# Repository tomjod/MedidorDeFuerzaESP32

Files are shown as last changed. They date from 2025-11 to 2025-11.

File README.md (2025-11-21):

# Medidor de Fuerza H:Q (Isquiotibiales / Cuádriceps)

## Descripción del Proyecto

Este proyecto consiste en un dispositivo electrónico diseñado para la medición, visualización y análisis de la fuerza muscular, específicamente enfocado en la relación (ratio) entre los músculos Isquiotibiales y Cuádriceps. Es una herramienta orientada a la evaluación biomecánica y rehabilitación deportiva.

El sistema utiliza celdas de carga para medir la fuerza ejercida en tiempo real, procesa los datos mediante un microcontrolador ESP32 y presenta los resultados en una pantalla de alta resolución con una interfaz gráfica moderna. Además, transmite los datos vía Bluetooth para su registro y análisis externo.

## Componentes de Hardware

### Microcontrolador

- **ESP32 DevKit V1**: Seleccionado por su doble núcleo (potencia de procesamiento), conectividad Bluetooth nativa y gran cantidad de pines GPIO.

### Sensores

- **2x Celdas de Carga (Tipo S)**: Transductores que convierten la fuerza física en una señal eléctrica diferencial.
- **2x Módulos HX711**: Amplificadores de instrumentación de 24-bits que digitalizan la señal de las celdas de carga para que el ESP32 pueda leerla con alta precisión.

### Visualización

- **Pantalla TFT ST7789 (170x320 píxeles)**: Pantalla IPS a color de alta densidad. Se eligió por su excelente ángulo de visión y capacidad de refresco rápido.

### Interfaz Física

- **Botón de Tara**: Para calibrar el cero de los sensores antes de la medición.
- **LEDs Indicadores**:
  - LED Estado (Heartbeat).
  - LED Bluetooth (Indica conexión activa).

## Diagrama de Conexiones (Pinout)

| Componente | Pin Dispositivo | Pin ESP32 | Descripción |
| :--- | :--- | :--- | :--- |
| **Sensor Isquios** | DAT | GPIO 19 | Datos HX711 |
| | CLK | GPIO 5 | Reloj HX711 |
| **Sensor Cuads** | DAT | GPIO 21 | Datos HX711 |
| | CLK | GPIO 22 | Reloj HX711 |
| **Pantalla ST7789** | SDA | GPIO 13 | Serial Data |
| | SCL | GPIO 14 | Serial Clock |
| | CS | (No conectado) | Chip Select (Opcional) |
| | DC | GPIO 26 | Data/Command |
| | RST | GPIO 27 | Reset |
| **Controles** | Botón Tara | GPIO 32 | Pull-up interno activado |
| | LED Estado | GPIO 4 | Indicador de funcionamiento |
| | LED Bluetooth | GPIO 23 | Indicador de conexión |

## Arquitectura de Software y Librerías

El firmware está desarrollado en C++ utilizando el framework Arduino sobre PlatformIO. Se han seleccionado librerías específicas para garantizar rendimiento y estabilidad:

### 1. `TFT_eSPI` (Bodmer)

- **Por qué se usa**: Es la librería gráfica más rápida disponible para el ESP32. Permite el uso de **Sprites** (buffers de memoria de video), lo que elimina el parpadeo ("flicker") al actualizar la pantalla.
- **Implementación**: Se dibuja toda la interfaz (medidores, textos, arcos) en un Sprite de 320x170 píxeles en la memoria RAM y luego se envía de golpe a la pantalla (DMA), logrando animaciones fluidas.

### 2. `HX711_ADC` (Olkal)

- **Por qué se usa**: A diferencia de la librería HX711 estándar, esta versión es **no bloqueante**. Permite leer los sensores sin detener el resto del programa (como la actualización de la pantalla o el Bluetooth).
- **Características**: Incluye algoritmos de suavizado (smoothing) para reducir el ruido eléctrico y estabilizar la lectura del peso.

### 3. `BluetoothSerial` (Nativa)

- **Por qué se usa**: Implementa el protocolo Bluetooth Clásico (SPP - Serial Port Profile), permitiendo que el dispositivo se comunique con teléfonos Android o PCs como si fuera un cable serial. Ideal para enviar datos de telemetría en tiempo real.

### 4. `Preferences` (Nativa)

- **Por qué se usa**: Reemplaza a la antigua EEPROM. Permite guardar los factores de calibración en la memoria no volátil (NVS) del ESP32, asegurando que la calibración no se pierda al apagar el dispositivo.

## Lógica de Funcionamiento

1. **Inicialización**: Al encender, el sistema carga la calibración guardada, inicia la pantalla y tara (pone a cero) los sensores.
2. **Bucle Principal (Loop)**:
    - **Lectura**: Lee los sensores HX711.
    - **Filtrado (Deadzone)**: Se aplica un umbral mínimo de **3 Newtons**. Cualquier fuerza menor a esto se considera ruido y se muestra como 0N.
    - **Cálculo**: Convierte la señal eléctrica a Newtons usando el factor de calibración y la constante de gravedad (9.81).
    - **Ratio H:Q**: Calcula la relación `Fuerza Isquios / Fuerza Cuádriceps`.
        - *Ejemplo*: Si Isquios = 100N y Cuads = 200N, Ratio = 0.5.
    - **Visualización**: Dibuja dos medidores circulares ("Gauges") y el valor numérico central. El color del ratio cambia según si está en un rango saludable o no.
    - **Transmisión**: Envía un paquete de datos binarios por Bluetooth para ser graficado en una App externa.

## Instrucciones de Uso

1. **Encendido**: Conectar el dispositivo a una fuente USB o batería.
2. **Tara**: Asegurarse de que no haya carga en los sensores y presionar el **Botón de Tara**. La pantalla indicará "Tarando...".
3. **Medición**: Aplicar fuerza en los sensores. Los gráficos se llenarán en tiempo real.
4. **Conexión App**:
    - Buscar dispositivo Bluetooth "ESP32_Fuerza_HQ".
    - Conectar desde la aplicación de análisis.
    - El LED de Bluetooth se encenderá fijo.

## Calibración (Técnica)

El sistema permite calibración remota vía comandos Serial/Bluetooth:

- `t`: Tarar sensores.
- `i=XXXX.X`: Establecer factor de calibración para Isquios.
- `q=XXXX.X`: Establecer factor de calibración para Cuádriceps.
- `save`: Guardar configuración en memoria permanente.

---

*Proyecto desarrollado por Alexis Ocando para Andrea Zunino*

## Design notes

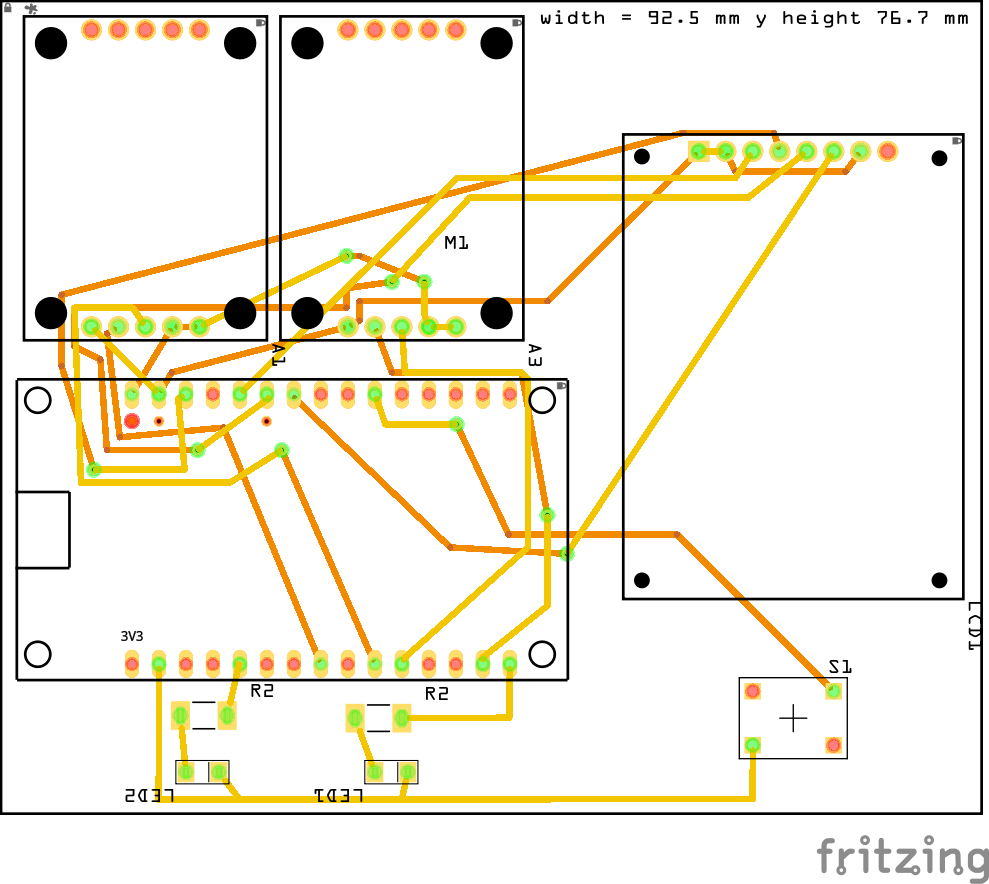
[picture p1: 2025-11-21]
pcb.png

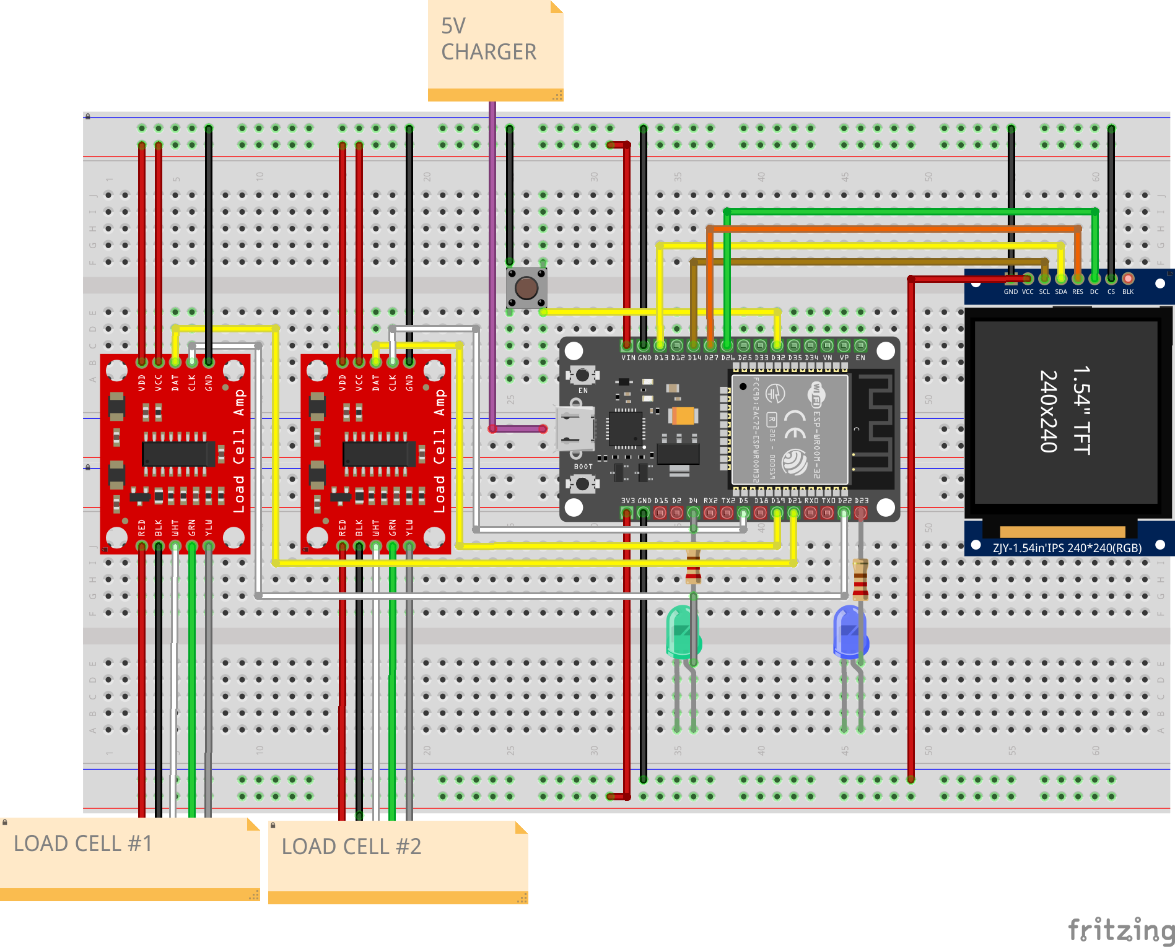
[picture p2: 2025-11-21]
protoboard_connection.png

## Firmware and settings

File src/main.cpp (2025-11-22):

/*
 * PROYECTO: Medidor de Fuerza H:Q (Isquios/Cuádriceps)
 * MCU: ESP32 DevKit V1
 * PANTALLA: ST7789 170x320
 * SENSORES: 2x Celdas de Carga "S" + 2x SparkFun HX711
 * CONTROLES: 1x Botón (Tara), 2x LEDs (Estado, BT)
 *
 * AUTOR: Ing. Alexis Ocando
 */
#include "BluetoothSerial.h" 

#if !defined(CONFIG_BT_ENABLED) || !defined(CONFIG_BLUEDROID_ENABLED)
#error Bluetooth is not enabled! Please run `make menuconfig` to and enable it
#endif
 
#if !defined(CONFIG_BT_SPP_ENABLED)
#error Serial Bluetooth not available or not enabled. It is only available for the ESP32 chip.
#endif

// --- LIBRERÍAS ---
#include <Arduino.h>
#include <HX711_ADC.h> // Librería avanzada para los sensores
#include <TFT_eSPI.h>  // Librería optimizada para la pantalla
#include <SPI.h>
#include <Preferences.h> // Para guardar calibración en NVS


// --- CONFIGURACIÓN DE PINES (SENSORES) ---
const int PIN_ISQUIOS_DAT = 19;
const int PIN_ISQUIOS_CLK = 5;
const int PIN_CUADS_DAT = 21;
const int PIN_CUADS_CLK = 22;

// --- CONFIGURACIÓN DE PINES (CONTROLES) ---
const int PIN_BTN_TARE = 32;
const int PIN_LED_STATUS = 4;  
const int PIN_LED_BT = 23;    

// --- OBJETOS GLOBALES ---
TFT_eSPI tft = TFT_eSPI();
TFT_eSprite sprite = TFT_eSprite(&tft);
BluetoothSerial SerialBT;
HX711_ADC sensorIsquios(PIN_ISQUIOS_DAT, PIN_ISQUIOS_CLK);
HX711_ADC sensorCuads(PIN_CUADS_DAT, PIN_CUADS_CLK);
Preferences preferences;

// --- CALIBRACIÓN ---
volatile float CAL_FACTOR_ISQUIOS = 43082.0; // Compr
volatile float CAL_FACTOR_CUADS = 43540.0;   

// --- VARIABLES GLOBALES (TIMERS) ---
unsigned long lastDisplayTime = 0;
const int DISPLAY_INTERVAL_MS = 100; // 10 FPS

unsigned long lastLedBlinkTime = 0;
unsigned long lastLedBtTime = 0;
const int LED_BLINK_INTERVAL_MS = 1000; // 1 segundo
bool ledStatusState = LOW;
bool ledBTState = LOW;
bool lastBTState = false;
float ratio = 0.0;

// --- VARIABLES GLOBALES (BOTÓN DEBOUNCE) ---
int lastButtonState = HIGH;
unsigned long lastDebounceTime = 0;
const int DEBOUNCE_DELAY_MS = 100;

// --- MODO CALIBRACIÓN ---
bool calibrationMode = false;

// --- DEFINICIÓN DEL PAQUETE BINARIO ---
#define STX 0x02 // STX
#define ETX 0x03 // ETX
#define PAYLOAD_LEN 8 // 2 floats * 4 bytes/float = 8 bytes

const float GRAVITY = 9.81; // Factor de conversión Kg -> Newtons

// --- Declaraciones de funciones ---
void initDisplay();
void initSensors();
void initControls();
void initBluetooth();
void tareSensors();
void handleTareButton();
void handleLEDs();
void handleBluetooth();
void handleSensorDisplay();
void updateBTdisplay();
void drawStaticUI();
void loadCalibration(); 
void saveCalibration(); 
void sendBinaryData(float f_isquios, float f_cuads);
void updateDisplay(float fuerzaIsquios, float fuerzaCuads);
void showCalibrationScreen();



//=================================================================
//  SETUP
//=================================================================
void setup() {
  Serial.begin(19200);
  Serial.println("Iniciando Medidor de Fuerza H:Q (v2.1)...");

  // Cargo la calibración que tengo guardada
  preferences.begin("fuerza-hq", false); // false = read/write
  loadCalibration();

  initControls(); // LEDs y botón
  initDisplay();
  // BT
  initBluetooth();
  initSensors();

}

//=================================================================
//  LOOP
//=================================================================
void loop() {
  
  // 1. Botón de tara (con debounce)
  handleTareButton();

  // 2. Comandos por BT
  handleBluetooth();
  
  // 3. LEDs de estado
  handleLEDs();
  
  // 4. Leer sensores y actualizar pantalla
  handleSensorDisplay();

  // 5. Estado de BT
  updateBTdisplay();

  delay(10);
}

//=================================================================
//  FUNCIONES DE INICIALIZACIÓN
//=================================================================

void initControls() {
  pinMode(PIN_LED_STATUS, OUTPUT);
  pinMode(PIN_LED_BT, OUTPUT);
  pinMode(PIN_BTN_TARE, INPUT_PULLUP); 
}

void initDisplay() {
  tft.init();
  tft.setRotation(1); 
  tft.fillScreen(TFT_BLACK);
  tft.setTextColor(TFT_WHITE, TFT_BLACK); 
  tft.setTextSize(2);
  tft.println("Iniciando...");  
  sprite.createSprite(320, 170);
  delay(1000);
}

void initSensors() {
  Serial.println("Iniciando sensores...");
  tft.println("Iniciando sensores...");

  sensorIsquios.begin();
  sensorIsquios.setGain(128);
  sensorIsquios.setCalFactor(CAL_FACTOR_ISQUIOS);
  sensorIsquios.setReverseOutput(); // Invertir salida para tracción
  sensorIsquios.start(2000, true); // 2s para estabilizar
  if (sensorIsquios.getTareTimeoutFlag()) {
    Serial.println("Error S1 Timeout");
    tft.println("Error S1 Timeout");
  }

  sensorCuads.begin();
  sensorCuads.setGain(128);
  sensorCuads.setCalFactor(CAL_FACTOR_CUADS);
  sensorCuads.setReverseOutput(); // Invertir salida para tracción
  sensorCuads.start(2000, true); // 2s para estabilizar
  if (sensorCuads.getTareTimeoutFlag()) {
    Serial.println("Error S2 Timeout");
    tft.println("Error S2 Timeout");
  }

  // Espero a que estén listos
  unsigned long startWait = millis();
  while(millis() - startWait < 3000) { 
    sensorIsquios.update();
    sensorCuads.update();
    if(sensorIsquios.getDataSetStatus() && sensorCuads.getDataSetStatus()) break;
    delay(10);
  }

  Serial.println("Sensores tarados y listos.");
  delay(1000);
  tft.fillScreen(TFT_BLACK);
}

void initBluetooth() {
  Serial.println("Iniciando Bluetooth...");
  tft.println("Iniciando Bluetooth...");
  if (SerialBT.begin("ESP32_Fuerza_HQ")) {
    Serial.println("Bluetooth iniciado. Listo para conectar.");
  }
  delay(1000);
}

//=================================================================
//  FUNCIONES PRINCIPALES
//=================================================================

// Reviso el botón de tara con debounce
void handleTareButton() {
  int reading = digitalRead(PIN_BTN_TARE);
  
  if (reading != lastButtonState) {
    lastDebounceTime = millis();
    lastButtonState = reading;
  }

  if ((millis() - lastDebounceTime) > DEBOUNCE_DELAY_MS) {
    if (lastButtonState == LOW) {
      tareSensors();
    }
  }
}

// Reviso comandos que llegan por Serial o BT
void handleBluetooth() {
  char cmdChar = ' ';
  String cmdString = "";

  // Desde la PC
  if (Serial.available() > 0) {
    cmdString = Serial.readStringUntil('\n');
    cmdChar = cmdString.charAt(0); // Para compatibilidad con 't'
  }
  
  // Desde el teléfono
  if (SerialBT.available() > 0) {
    cmdString = SerialBT.readStringUntil('\n');
    cmdChar = cmdString.charAt(0); // Para compatibilidad con 't'
  }

  // Proceso el comando
  cmdString.trim();

  if (cmdChar == 't') { // Comando de Tara
    tareSensors();
  }
  else if (cmdString.startsWith("i=")) { // Ajustar Isquios
    float nuevoFactor = cmdString.substring(2).toFloat();
    if (nuevoFactor > 1000) { 
      CAL_FACTOR_ISQUIOS = nuevoFactor;
      sensorIsquios.setCalFactor(CAL_FACTOR_ISQUIOS); 
      Serial.print("Nuevo factor Isquios: ");
      Serial.println(CAL_FACTOR_ISQUIOS);
    }
  }
  else if (cmdString.startsWith("q=")) { // Ajustar Cuádriceps
    float nuevoFactor = cmdString.substring(2).toFloat();
    if (nuevoFactor > 1000) { 
      CAL_FACTOR_CUADS = nuevoFactor;
      sensorCuads.setCalFactor(CAL_FACTOR_CUADS);
      Serial.print("Nuevo factor Cuads: ");
      Serial.println(CAL_FACTOR_CUADS);
    }
  }
  else if (cmdString == "save") { // Guardar
    saveCalibration();
  }
  else if (cmdString == "load") { // Recargar
    loadCalibration();
  }
  else if (cmdString == "cal") { // Modo Calibración
    calibrationMode = !calibrationMode;
    if (calibrationMode) {
      Serial.println("Modo Calibración ACTIVADO - Mostrando valores RAW");
      if (SerialBT.connected()) {
        SerialBT.println("Modo Calibración ACTIVADO");
      }
    } else {
      Serial.println("Modo Calibración DESACTIVADO");
      if (SerialBT.connected()) {
        SerialBT.println("Modo Calibración DESACTIVADO");
      }
      tft.fillScreen(TFT_BLACK);
    }
  }
}

// LEDs de estado
void handleLEDs() {
  // LED BT: encendido si está conectado
  if (SerialBT.connected()) {
    digitalWrite(PIN_LED_BT, HIGH);
  } else {
    if (millis() - lastLedBtTime >= (LED_BLINK_INTERVAL_MS - 500)) {
      lastLedBtTime = millis();
      ledBTState = !ledBTState;
      digitalWrite(PIN_LED_BT, ledBTState );
    }
  }

  if (!ledStatusState) {
    digitalWrite(PIN_LED_STATUS, HIGH);
    ledStatusState = true;
  } 
}

// Leo sensores, actualizo pantalla y mando data por BT
void handleSensorDisplay() {
  if (millis() - lastDisplayTime >= DISPLAY_INTERVAL_MS) {
    lastDisplayTime = millis();
    sensorIsquios.update();
    sensorCuads.update();

    // Si estoy en modo calibración, muestro valores RAW
    if (calibrationMode) {
      showCalibrationScreen();
      return;
    }

    // Obtengo el valor y lo paso a Newtons
    float rawIsquios = sensorIsquios.getData() * GRAVITY;
    float rawCuads = sensorCuads.getData() * GRAVITY;

    // Deadzone de 3N para filtrar ruido
    float fuerzaIsquios = (rawIsquios > 3.0) ? rawIsquios : 0.0f;
    float fuerzaCuads = (rawCuads > 3.0) ? rawCuads : 0.0f;

    // Actualizo pantalla
    updateDisplay(fuerzaIsquios, fuerzaCuads);

    // Mando por BT
    sendBinaryData(fuerzaIsquios, fuerzaCuads);

  }
}

//=================================================================
//  FUNCIONES DE ACCIÓN
//=================================================================

// Tara de los sensores
void tareSensors() {
  Serial.println("Tarando sensores...");
  tft.fillScreen(TFT_BLACK);
  tft.setCursor(tft.width() / 2 - 50, tft.height() / 2 - 10);
  tft.setTextSize(2);
  tft.setTextColor(TFT_WHITE, TFT_BLACK);
  tft.println("Tarando...");
  
  sensorIsquios.tare();
  sensorCuads.tare();

  delay(500); 
  tft.fillScreen(TFT_BLACK);
  Serial.println("Tara completa.");
  
  // Confirmo por BT
  if(SerialBT.connected()) {
    SerialBT.println("Tara Completa");
    SerialBT.write(0x06); // ACK
    SerialBT.flush();
  }
}

// Dibujo un gauge circular
void drawGauge(int x, int y, int r, float val, float maxVal, uint16_t color, String label, String units) {
  int ir = r - 10;
  int startAngle = 135;
  int endAngle = 45;
  
  // Fondo
  sprite.drawSmoothArc(x, y, r, ir, startAngle, endAngle, TFT_DARKGREY, TFT_BLACK, true);

  // Mapeo el valor a un ángulo (270 grados de recorrido)
  
  float percentage = val / maxVal;
  if (percentage > 1.0) percentage = 1.0;
  
  int arcLength = 270;
  int currentEndAngle = startAngle + (int)(percentage * arcLength);
  if (currentEndAngle >= 360) currentEndAngle -= 360;

  // Arco con el valor actual
  if (val > 0.5) { 
      sprite.drawSmoothArc(x, y, r, ir, startAngle, currentEndAngle, color, TFT_BLACK, true);
  }

  // Valor
  sprite.setTextDatum(MC_DATUM); // Middle Center
  sprite.setTextColor(TFT_WHITE, TFT_BLACK);
  sprite.setTextSize(3);
  sprite.drawString(String(val, 0), x, y);
  
  // Unidades
  sprite.setTextSize(1);
  sprite.setTextColor(TFT_LIGHTGREY, TFT_BLACK);
  sprite.drawString(units, x, y + 20);

  // Título
  sprite.setTextSize(2);
  sprite.setTextColor(color, TFT_BLACK);
  sprite.drawString(label, x, y - r - 15);
}

// Dibujo todo en la pantalla
void updateDisplay(float fuerzaIsquios, float fuerzaCuads) {
  
  sprite.fillSprite(TFT_BLACK);

  // Dimensiones de la pantalla
  int w = 320;
  int h = 170;
  
  // Posiciones de los gauges
  int r = 55; // Radio
  int yCenter = h / 2 + 10;
  int xLeft = 70;
  int xRight = w - 70;

  // 1. Gauge Isquios (Izquierda)
  drawGauge(xLeft, yCenter, r, fuerzaIsquios, 1000.0, TFT_CYAN, "ISQUIOS", "N");

  // 2. Gauge Cuads (Derecha)
  drawGauge(xRight, yCenter, r, fuerzaCuads, 1000.0, TFT_ORANGE, "CUADS", "N");

  // 3. Ratio (Centro)
  //sprite.setTextDatum(MC_DATUM);
  //sprite.setTextColor(TFT_WHITE, TFT_BLACK);
  
  //sprite.setTextSize(1);
  //sprite.drawString("RATIO H:Q", w/2, yCenter - 20);
  
  //sprite.setTextSize(4);
  // Color según el rango (0.6 es bueno)
  //uint16_t ratioColor = TFT_WHITE;
  //if(ratio >= 0.55 && ratio <= 0.75) ratioColor = TFT_GREEN;
  //else if (ratio > 0.0) ratioColor = TFT_RED;
  
  //sprite.setTextColor(ratioColor, TFT_BLACK);
  //sprite.drawFloat(ratio, 2, w/2, yCenter + 10);

  // 4. Estado Bluetooth
  sprite.setTextSize(1);
  sprite.setTextDatum(TR_DATUM); // Top Right
  if (SerialBT.connected()) {
    sprite.setTextColor(TFT_BLUE, TFT_BLACK);
    sprite.drawString("BT: ON", w - 5, 5);
  } else {
    sprite.setTextColor(TFT_DARKGREY, TFT_BLACK);
    sprite.drawString("BT: --", w - 5, 5);
  }

  // Mando todo a la pantalla
  sprite.pushSprite(0, 0);
}


void sendBinaryData(float f_isquios, float f_cuads) {
  if (!SerialBT.connected()) {
    return;
  }
  
  // buffer del payload (12 bytes)
  byte payload[PAYLOAD_LEN];
  
  // Copio los floats al buffer
  memcpy(payload, &f_isquios, 4);
  memcpy(payload + 4, &f_cuads, 4);

  // Checksum
  byte checksum = 0;
  for (int i = 0; i < PAYLOAD_LEN; i++) {
    checksum ^= payload[i];
  }

  // Mando el paquete
  SerialBT.write(STX);
  SerialBT.write(PAYLOAD_LEN);
  SerialBT.write(payload, PAYLOAD_LEN);
  SerialBT.write(checksum);
  SerialBT.write(ETX);
}

// Cargo la calibración desde la memoria
void loadCalibration() {
  Serial.println("Cargando calibracion desde NVS...");
  // Si no hay nada guardado, uso los valores por defecto
  CAL_FACTOR_ISQUIOS = preferences.getFloat("cal_isquios", CAL_FACTOR_ISQUIOS);
  CAL_FACTOR_CUADS = preferences.getFloat("cal_cuads", CAL_FACTOR_CUADS);

  Serial.print("Factor Isquios: "); Serial.println(CAL_FACTOR_ISQUIOS);
  Serial.print("Factor Cuads: "); Serial.println(CAL_FACTOR_CUADS);

  // Aplico los factores
  sensorIsquios.setCalFactor(CAL_FACTOR_ISQUIOS);
  sensorCuads.setCalFactor(CAL_FACTOR_CUADS);
}

// Actualizo el estado de Bluetooth y manejo reconexiones
void updateBTdisplay() {
  bool currentBTState = SerialBT.connected();
  
  // Detecto si hubo una desconexión
  if (lastBTState && !currentBTState) {
    Serial.println("Bluetooth desconectado. Reiniciando servicio...");
    
    // Termino la conexión actual para liberar el socket
    SerialBT.end();
    delay(500); // Espero a que se libere completamente
    
    // Reinicio el servicio Bluetooth
    if (SerialBT.begin("ESP32_Fuerza_HQ")) {
      Serial.println("Bluetooth reiniciado. Listo para nueva conexión.");
    } else {
      Serial.println("Error al reiniciar Bluetooth");
    }
  }
  
  // Actualizo el estado anterior
  lastBTState = currentBTState;
}

// Guardo la calibración en la memoria
void saveCalibration() {
  Serial.println("Guardando calibracion en NVS...");
  preferences.putFloat("cal_isquios", CAL_FACTOR_ISQUIOS);
  preferences.putFloat("cal_cuads", CAL_FACTOR_CUADS);

  tft.setTextSize(2);
  tft.setTextColor(TFT_GREEN, TFT_BLACK);
  tft.setCursor(10, tft.height() / 2);
  tft.print("¡Calibracion Guardada!");
  delay(1000);
}

// Pantalla de calibración con valores RAW
void showCalibrationScreen() {
  // Obtengo valores calibrados (en kg)
  float dataIsquios = sensorIsquios.getData(); // En kg (ya calibrado)
  float dataCuads = sensorCuads.getData();     // En kg (ya calibrado)
  
  // Obtengo el offset de tara y factores de calibración
  long tareIsquios = sensorIsquios.getTareOffset();
  long tareCuads = sensorCuads.getTareOffset();
  float calIsquios = sensorIsquios.getCalFactor();
  float calCuads = sensorCuads.getCalFactor();
  
  // Calculo el valor RAW del ADC: RAW = (getData() * calFactor) + tareOffset
  long rawIsquios = (long)(dataIsquios * calIsquios) + tareIsquios;
  long rawCuads = (long)(dataCuads * calCuads) + tareCuads;

  sprite.fillSprite(TFT_BLACK);
  
  // Título
  sprite.setTextDatum(TC_DATUM);
  sprite.setTextSize(2);
  sprite.setTextColor(TFT_YELLOW, TFT_BLACK);
  sprite.drawString("MODO CALIBRACION", 160, 5);
  
  // Línea divisoria
  sprite.drawLine(10, 30, 310, 30, TFT_DARKGREY);
  
  // SENSOR ISQUIOS
  sprite.setTextDatum(TL_DATUM);
  sprite.setTextSize(2);
  sprite.setTextColor(TFT_CYAN, TFT_BLACK);
  sprite.drawString("ISQUIOS (Traccion)", 10, 38);
  
  sprite.setTextSize(1);
  sprite.setTextColor(TFT_LIGHTGREY, TFT_BLACK);
  sprite.drawString("RAW ADC: " + String(rawIsquios), 10, 58);
  sprite.drawString("Tare: " + String(tareIsquios), 170, 58);
  
  sprite.setTextColor(TFT_WHITE, TFT_BLACK);
  sprite.drawString("Cal: " + String(calIsquios, 0), 10, 73);
  sprite.drawString("kg: " + String(dataIsquios, 3), 10, 88);
  sprite.drawString("N: " + String(dataIsquios * GRAVITY, 1), 170, 88);
  
  // Línea divisoria
  sprite.drawLine(10, 105, 310, 105, TFT_DARKGREY);
  
  // SENSOR CUÁDRICEPS
  sprite.setTextSize(2);
  sprite.setTextColor(TFT_ORANGE, TFT_BLACK);
  sprite.drawString("CUADRICEPS (Compresion)", 10, 113);
  
  sprite.setTextSize(1);
  sprite.setTextColor(TFT_LIGHTGREY, TFT_BLACK);
  sprite.drawString("RAW ADC: " + String(rawCuads), 10, 133);
  sprite.drawString("Tare: " + String(tareCuads), 170, 133);
  
  sprite.setTextColor(TFT_WHITE, TFT_BLACK);
  sprite.drawString("Cal: " + String(calCuads, 0), 10, 148);
  sprite.drawString("kg: " + String(dataCuads, 3), 10, 163);
  sprite.drawString("N: " + String(dataCuads * GRAVITY, 1), 170, 163);
  
  // Muestro en pantalla
  sprite.pushSprite(0, 0);
  
  // También envío por Serial para debugging detallado
  Serial.print("ISQ-> RAW:");
  Serial.print(rawIsquios);
  Serial.print(" Tare:");
  Serial.print(tareIsquios);
  Serial.print(" Cal:");
  Serial.print(calIsquios, 0);
  Serial.print(" kg:");
  Serial.print(dataIsquios, 3);
  Serial.print(" N:");
  Serial.print(dataIsquios * GRAVITY, 2);
  
  Serial.print(" || CUA-> RAW:");
  Serial.print(rawCuads);
  Serial.print(" Tare:");
  Serial.print(tareCuads);
  Serial.print(" Cal:");
  Serial.print(calCuads, 0);
  Serial.print(" kg:");
  Serial.print(dataCuads, 3);
  Serial.print(" N:");
  Serial.println(dataCuads * GRAVITY, 2);
}

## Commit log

2025-11-17 Se mejoro la posicion de los estados en la pantalla
    Se agrego funciones para guardar calibracion desde el serial o bluetooth
2025-11-21 documentación para release
2025-11-21 docs: Refine ST7789 pin labels and descriptions in README.
2025-11-21 feat: Add initial Fritzing design file and PCB/protoboard connection images.
    [medidor_fuerza.fzz]
2025-11-21 feat: update force meter Fritzing design
    [medidor_fuerza.fzz]
2025-11-22 feat: Add calibration mode to display raw sensor data, invert sensor output, and adjust serial speed and data payload.
    [main.cpp]
